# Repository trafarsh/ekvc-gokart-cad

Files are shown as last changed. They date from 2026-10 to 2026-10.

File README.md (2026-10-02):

# EKVC Season 4 – 10 engine-kart concepts (side-mounted Yamaha R15 V2)

Ten complete, rule-checked go-kart designs for the **Engine/Electric Kart Vehicle Championship –
Season 4** rulebook, generated parametrically from the team's Ackermann/layout sketch
(`therika2` / `mutusami_sterring.SLDPRT`).

Each style is a full kart: chromoly frame and roll hoop, **front, rear and side bumpers**,
**chassis-to-bumper connectors**, **single-disc hydraulic brake**, live axle and chain drive, the
R15 V2 engine on the right, Ackermann steering, CBA pedal box, seat, firewall, floor pan, bodywork,
kill switches, brake light, extinguisher, fuel tank, radiator, exhaust, and hitch points.

| | Common to all 10 styles |
|---|---|
| Overall length | **64.1 – 64.6 in bumper face to bumper face, foam included** (limit < 65 in, ≥ 11 mm margin on every kart); nothing protrudes beyond the bumpers |
| Wheelbase / track | 46.0 – 47.0 in wheelbase; front track 36 – 38 in, rear track 42.0 – 42.8 in (rear stays under 50 in even over the tyres) |
| Frame tube | **AISI 4130 chromoly, seamless, 25.4 × 1.65 mm** (rule: 1–2 in OD, ≥ 1.2 mm wall, C ≥ 0.18 %) |
| Engine | Yamaha R15 V2, 149.8 cc single-cylinder 4-stroke, liquid cooled – mounted on the **right**, chain on its inboard side |
| Drive | #428 chain 14T / 34T (66 links), live 40 mm axle, 3 flange bearings |
| Brake | Hydraulic, one 180 mm disc on the live axle (locks both rear wheels), 5/8 in master cylinder with own reservoir, over-travel switch |
| Steering | Column + pitman arm + 2 tie rods, knuckle arms tuned per style for ~100 % Ackermann at lock (computed at the real rod-end ball centres), outer-wheel turning radius ≈ 2.8 m (rule ≤ 3 m), 280 mm round wheel, positive stops on the chassis at 52° column rotation (full lock 49–51°) |
| Driver | Designed around a 175 cm driver: back angle 20°, roll-hoop top 115 mm above the helmet (rule ≥ 76 mm), foot guard 92 mm above the toes (rule ≥ 76 mm) |
| Tyres | 4.5×10.0-5 front, 7.1×11.0-5 rear (rule table 1, dry D1) |

## The ten styles

| Code | Name | Frame idea | Front / rear / side bumpers | Body |
|---|---|---|---|---|
| S01 | Classic Sprint | straight rails, 3-cross ladder | straight / straight / bar | box nose & pods |
| S02 | Arrow | rails taper into the nose + arrow-shaped outer rails | chevron / arc / kicked bar | arrow nose, wedge pods |
| S03 | Ladder Pro | 5-cross ladder + upper side-impact rails | U (up-turned ends) / U / twin-bar | box |
| S04 | Bowfin | left rail bowed outward + floor X | arc / arc / arc | round |
| S05 | X-Brace | X bracing in cockpit and engine bay | trapezoid / trapezoid / bar | wedge |
| S06 | Perimeter | outer perimeter rails carry the side bumpers | wide straight / straight / hoop | box nose, full pods |
| S07 | Spine | centre spine + V outriggers | chevron / straight / bar | F1 nose, slim pods |
| S08 | Endurance | ladder + upper rails + floor/foot-guard/engine-bay diagonals | U / U / twin-bar | round nose, full pods |
| S09 | Featherweight | minimum members | straight / straight / bar | slim |
| S10 | Wedge | plan-view wedge outer rails | swept / arc / swept | wedge |

Each style folder has its own `README.md` with the full **rule-compliance table**, steering
data, interference-check results and renders (`output/<style>/renders/`).

**Check results (all ten styles):** 45 / 45 automated rule checks pass, **0 part-to-part clashes**
(intended welds and bolted joints excluded), **0 contacts** when both front tyres are swept
lock-to-lock against the frame, bumpers, connectors, steering and bodywork, and **0 contacts** when the
whole steering linkage (column, wheel, pitman arm, tie rods, knuckles, hubs, rims, tyres) is moved
lock-to-lock exactly as the SolidWorks live-steering mates move it. The 175 cm reference driver has
no interference with anything except the seat and steering-wheel grips.

## Getting SolidWorks `.SLDPRT` / `.SLDASM` files

SolidWorks' native format can only be written by SolidWorks itself, so every part is delivered
as a STEP file (AP214, millimetres, with names and colours) plus a macro that converts the whole
set inside SolidWorks in one run:

1. In SolidWorks: **Tools ▸ Options ▸ System Options ▸ Import** → untick **Enable 3D Interconnect**
   (so STEP files open as plain imported bodies). Optionally set *Import diagnostics* to "never".
2. **Tools ▸ Macro ▸ New…** (save the new macro anywhere) → in the VBA editor **File ▸ Import File…**
   → choose `solidworks_macro/EKVC_STEP_to_SLDPRT_and_SLDASM.bas` → run `main`.
3. When asked, paste the path of this repository's `output` folder.

The macro saves an `.SLDPRT` next to every `.step` and then builds
`output/<style>/<style>.SLDASM` for all ten karts from `placements.csv`, with every component
fixed in place. Re-running skips files that already exist.

*Quick alternative:* **File ▸ Open** any `output/<style>/<style>_ASSEMBLY.step` → SolidWorks imports
the whole kart as an assembly; **File ▸ Save As** then saves the `.SLDASM` and all part files
(this route gives a static assembly - no live steering).

### Live steering in SolidWorks (turn the wheel, the front wheels steer)

The macro also turns every `.SLDASM` into a working steering mechanism, using
`output/<style>/kinematics.csv`:

| Moving part | How it is mated |
|---|---|
| Steering column | revolute about the column axis (point coincident + point on axis, to the frame) |
| Steering wheel, pitman arm | locked to the column |
| Knuckle L / R | revolute about its king-pin axis |
| Front hub, rim, tyre | locked to their knuckle |
| Tie rod L / R | ball joint at each rod-end centre (pitman arm and knuckle arm) |
| Steering lock | `LimitDistance` mate stops the column at full lock (≈ ±49–51°) |

The joint points and axes are tiny 3D sketches named `KIN_...` that the macro adds to the frame,
column, pitman arm, knuckles and tie rods. **To steer: drag the steering wheel (or a front tyre) with the
left mouse button.** Everything else stays fixed. Hide the joint sketches with *View ▸ Hide/Show ▸ Sketches*.
For an animation, add a *Motion Study* with a rotary motor on the steering column.

Already built the assemblies? Run the macro entry **`live_steering`** instead of `main` to add only the
steering mates. If a mate cannot be made, the end-of-run message lists it (nothing else is changed).
If the steering will not turn at all, suppress the `LimitDistance1` mate: that mate is only the lock stop.

## Repository layout

```
output/
  common/parts/*.step              parts shared by all styles (engine, wheels, brake, pedals, seat ...)
                                   + loose items: C-STD-01 kart stand (rule 8, rails at 950 mm),
                                     C-HIT-02 yellow push-pull rod (rule 1.4)
  S01_ClassicSprint/
    S01_ClassicSprint_ASSEMBLY.step complete kart assembly
    parts/*.step                   style-specific parts (frame, bumpers, connectors, knuckles, body ...)
    placements.csv                 transform of every component (used by the macro)
    kinematics.csv                 joint points/axes + mates for live steering (used by the macro)
    BOM.csv                        bill of materials with materials and notes
    README.md                      rule-compliance report, steering data, clash results
    renders/*.png
  ... S02 – S10
solidworks_macro/EKVC_STEP_to_SLDPRT_and_SLDASM.bas
generator/                          Python/CadQuery source that builds everything
docs/                               source sketch analysis, rule interpretation notes
```

### Coordinate system (all parts and assemblies)

Origin on the ground, on the kart centre-line, directly under the rear axle.
**+X forward, +Y up, +Z to the driver's right (engine side).** Units: mm.
(SolidWorks shows +Y as up, so the karts open the right way up.)

## Regenerating / changing the designs

```bash
pip install cadquery
cd generator
python build_all.py            # all 10 styles with full checks (~25 min)
python build_all.py S04        # one style
python build_all.py --fast S04 # skip the slow interference check
```

Global parameters (tube size, driver package, engine position, steering arm length...) live in
`generator/ekvc/layout.py`; the ten styles are in `generator/ekvc/styles.py`; frame topologies in
`generator/ekvc/parts/frame.py`; bumpers and connectors in `generator/ekvc/parts/bumpers.py`.
Changing the tube (e.g. to AISI 1018, 25.4 × 2.0) is a two-line edit (`TUBE_WALL`, `TUBE_MAT`).

## Important assumptions – please verify

* **Engine envelope.** The R15 V2 is modelled as a dimensional envelope (crankcase, inclined
  cylinder, head, covers, countershaft, mounting lugs). Measure your engine and adjust
  `parts/wheels_drive.py:engine()` and the mount positions before cutting tabs.
* **Your sketch was a 2D layout.** Its wheelbase (51 in) and overall length (73.3 in) did not fit the
  65 in limit, so the wheelbase was shortened to 46–47 in and the Ackermann arm angle re-solved per
  style. The king-pin offset from the wheel (3.52 in) and tyre sizes come from your sketch.
* **Track width rule.** "Larger track ≤ 50 in" is satisfied centre-to-centre *and* over the tyre
  sidewalls (49.9 in max), in case judges measure outside-to-outside.
* **Hoop braces** run rearward from the hoop bend (650 mm) to the rear bulkhead. If your scrutineers
  want them attached higher, raise `HOOP_KNEE_Y` in `layout.py`.
* Bodywork is a 3 mm shell for fit/visual purposes; real panels need mounting brackets.
* Bumper foam is modelled as a continuous sleeve; in practice slit it around the connector tabs and bolts.
* The orange manikin (`REF driver`) is reference geometry only – suppress it before drawings/BOM.
* The live-steering macro was written against the SolidWorks API but could not be run here (no
  SolidWorks in the build environment); the motion it reproduces is verified in Python (see the
  linkage sweep in each style's `README.md`).

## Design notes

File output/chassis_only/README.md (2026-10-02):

# Chassis only - all 10 styles

One STEP part per kart: the welded chromoly frame with roll hoop, hoop braces, foot guard, bulkheads, front axle beam with king-pin C-brackets, jack pads, radiator tabs and the chassis-side bumper connector tabs. No bumpers, bodywork or components.

Tube: AISI 4130 chromoly, seamless, 25.4 x 1.65 mm. Coordinates are the same as the full karts (origin on the ground under the rear axle, +X forward, +Y up, +Z right), so each chassis drops straight into the kart assembly.

**To get .SLDPRT:** SolidWorks > File > Open > pick the .step > File > Save As > Part (*.sldprt). It opens as a multi-body part (one body per tube / plate), like a weldment.

| Kart | File | Tube bodies + plates | Connector tabs | Size L x H x W (mm) | Tube length | Tube mass |
|---|---|---|---|---|---|---|
| S01 Classic Sprint | `S01_ClassicSprint_Chassis.step` | 33 | 8 | 1555 x 1035 x 1186 | 17.8 m | 17.2 kg |
| S02 Arrow | `S02_Arrow_Chassis.step` | 33 | 8 | 1550 x 1035 x 1185 | 18.3 m | 17.7 kg |
| S03 Ladder Pro | `S03_LadderPro_Chassis.step` | 36 | 8 | 1555 x 1035 x 1186 | 19.6 m | 19.0 kg |
| S04 Bowfin | `S04_Bowfin_Chassis.step` | 34 | 8 | 1550 x 1035 x 1231 | 18.3 m | 17.7 kg |
| S05 X-Brace | `S05_X-Brace_Chassis.step` | 37 | 8 | 1553 x 1035 x 1185 | 19.7 m | 19.0 kg |
| S06 Perimeter | `S06_Perimeter_Chassis.step` | 35 | 8 | 1555 x 1035 x 1186 | 19.3 m | 18.6 kg |
| S07 Spine | `S07_Spine_Chassis.step` | 35 | 8 | 1549 x 1035 x 1185 | 18.5 m | 17.9 kg |
| S08 Endurance | `S08_Endurance_Chassis.step` | 39 | 8 | 1555 x 1035 x 1186 | 20.7 m | 20.0 kg |
| S09 Featherweight | `S09_Featherweight_Chassis.step` | 31 | 8 | 1547 x 1035 x 1185 | 16.9 m | 16.3 kg |
| S10 Wedge | `S10_Wedge_Chassis.step` | 33 | 8 | 1552 x 1035 x 1178 | 18.3 m | 17.7 kg |

Renders: `renders/` (iso, side, top for each kart; `all_chassis_iso.png` shows all ten).

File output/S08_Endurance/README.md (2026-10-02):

# S08 - Endurance

Heavily triangulated with upper side rails and diagonal floor braces; built for the endurance event.

* Wheelbase **47.00 in** (1193.8 mm), front track 37.50 in, rear track 42.80 in
* Frame: `endurance` - 20.7 m of 25.4 x 1.65 mm AISI 4130 chromoly, seamless (C 0.28-0.33 %) (~20.0 kg tube)
* Bumpers: front `U`, rear `U`, side `double`; body: nose `round`, pods `full`
* Steering: arm 155 mm at 15.25 deg, tie rods 277/396 mm (solver), lock inner 33.9 / outer 25.2 deg, R(outer front) 2.81 m, Ackermann 99 %

## Rule compliance (EKVC Season 4)

| Rule | Check | Requirement | This kart | Result |
|---|---|---|---|---|
| 1.1 | Wheelbase | <= 60 in (1524 mm) | 1193.8 mm (47.00 in) | ✅ PASS |
| 1.1 | Larger track (centre-to-centre) | <= 50 in (1270 mm) | 1087.1 mm (42.80 in) | ✅ PASS |
| 1.1 | Rear track outside-to-outside (conservative) | <= 50 in | 1267.5 mm (49.90 in) | ✅ PASS |
| 1.1 | Wheels not in line longitudinally | front track != rear track | F 952 / R 1087 mm | ✅ PASS |
| User | Front bumper to rear bumper (incl. foam) | < 65 in (1651 mm) | 1635.9 mm (64.41 in) | ✅ PASS |
| User | Overall length (any component) | < 65 in, nothing beyond bumpers | 1635.9 mm (64.41 in) | ✅ PASS |
| info | Overall width | (info) | 1320 mm (52.0 in) | ✅ PASS |
| 1.2 | Frame tube OD / wall | 1-2 in OD, >= 1.2 mm wall, seamless round | 25.4 x 1.65 mm, AISI 4130 chromoly, seamless (C 0.28-0.33 %) | ✅ PASS |
| 1.2 | Open tube end capped | >= 1 open end, capped | Silencer-stay end capped (6 mm plug) | ✅ PASS |
| 1.3 | Ground clearance (lowest non-tyre point) | 1-2 in (25.4-50.8 mm) | 35.0 mm (Firewall rear) | ✅ PASS |
| 1.4 | Hitch points | front + rear, not on bumper, yellow | 2 eyes on bulkhead tubes | ✅ PASS |
| 1.5 | Roll hoop height above helmet (175 cm driver) | >= 3 in (76.2 mm) | 115.0 mm | ✅ PASS |
| 1.5 | Roll hoop construction | one bent tube + 2 braces L/R | single bent tube, 2 rearward braces + cross bar | ✅ PASS |
| 1.6 | Front bumper ahead of front bulkhead | >= 4 in (101.6 mm) | 114.7 mm | ✅ PASS |
| 1.6 | Rear bumper behind rear bulkhead | >= 2 in (50.8 mm) | 56.8 mm | ✅ PASS |
| 1.6 | Bumpers cover tyres laterally | bumper reaches outer tyre edge | front +22 mm, rear +4 mm | ✅ PASS |
| 7.1.1 | No full-round bumper | side bumpers separate from front/rear | min X gap 344 mm | ✅ PASS |
| 1.6 | Bumper padding | foam pipe insulation | 12 mm closed-cell foam on all bumpers | ✅ PASS |
| 2.2 | Tyres | F 4.5x10.0-5, R 7.1x11.0-5 (D1) | as specified, 4 wheels | ✅ PASS |
| 3.1 | Seat | bucket seat, >= 4 mounts on primary members, lock nuts | GRP bucket, 4 mounts | ✅ PASS |
| 3.2 | Foot guard above toe | >= 3 in (76.2 mm) + anti-intrusion plate | 91.7 mm, 2 mm Al plate | ✅ PASS |
| 3.3 | Back angle | <= 30 deg from vertical | 20 deg | ✅ PASS |
| 3.5 | Firewall | >= 1.5 mm Al, no holes, nothing mounted | 1.5 mm 5052 side + rear panels | ✅ PASS |
| 4.1 | Steering mechanism | mechanical, no rack & pinion / by-wire | column + pitman arm + 2 tie rods (Ackermann) | ✅ PASS |
| 4.2 | Steering wheel | >= 10 in OD full circle | 280 mm round | ✅ PASS |
| 4.3 | Steering stops | positive stops on chassis | 2 adjustable stops on column lower bracket | ✅ PASS |
| 4.4 | Turning radius (outer front wheel) | <= 3 m | L 2.81 m / R 2.83 m | ✅ PASS |
| info | Ackermann at lock | (design target ~100 %) | 99 % (inner 33.9 / outer 25.2 deg) | ✅ PASS |
| 5.1 | Brake system | hydraulic, acts on both rear wheels | single 180 mm disc on live axle, twin-piston caliper | ✅ PASS |
| 5.2 | Brake pedal | foot operated, steel/Al, travel stop | AISI 4130 pedal with stop | ✅ PASS |
| 5.3 | Brake over-travel switch | in series with kill switches | fitted ahead of pedal | ✅ PASS |
| 5.6 | Brake light | red, top centre of roll hoop | LED on hoop top centre | ✅ PASS |
| 6.2.1 | Engine | single cyl 4-stroke petrol <= 160 cc | Yamaha R15 V2 149.8 cc liquid cooled | ✅ PASS |
| 6.2.2 | Engine mounting tabs | >= 5 mm + damping | 6 mm tabs + rubber isolators | ✅ PASS |
| 6.2.3 | Fuel tank | <= 3 L, side-engine fuel area | 2.79 L behind seat (left) | ✅ PASS |
| 6.2.3 | Radiator | behind firewall | behind rear firewall, above axle | ✅ PASS |
| 6.2.4 | Exhaust outlet | behind driver, <= 650 mm high | X -186 mm, height 370 mm | ✅ PASS |
| 6.4 | Transmission | chain drive, RWD, scatter shield | #428 chain 14/34, Al scatter shield | ✅ PASS |
| 6.4.2 | Pedal layout | C-B-A left to right, throttle stop | clutch / brake / throttle | ✅ PASS |
| 6.5 | Kill switches | >= 2 (driver + both sides of hoop), red | 3 fitted | ✅ PASS |
| 6.9 | Fire extinguisher | 1 kg in cockpit, not on firewall | 1 kg ABC on left main rail | ✅ PASS |
| 6.10 | Fasteners | metal, grade 8.8, lock nuts | M8 8.8 + nyloc on all connectors | ✅ PASS |
| 7.1 | Bodywork | front (to steering wheel), L/R sides, rear | nose + 2 pods + rear panel | ✅ PASS |
| 7.1.2 | Floor close-out | >= 1 mm rigid, firewall to front | 2.0 mm aluminium | ✅ PASS |
| 9 | Number stickers | 6 in yellow: front, both sides, rear | 4 fitted | ✅ PASS |

## Interference check

* Part-to-part clashes (excluding intended welds/bolted contacts): **0**
* Driver (175 cm reference manikin) contacts: 0
* Front tyres swept lock-to-lock against frame/bumpers/body/steering: **0** contacts
* Whole steering linkage (column, wheel, pitman arm, tie rods, knuckles, hubs, rims, tyres) moved lock-to-lock (column -50.8 to +50.8 deg), exactly as the SolidWorks live-steering mates move it: **0** new contacts

## Files

* Assembly STEP: `S08_Endurance_ASSEMBLY.step`
* Placement table (SolidWorks macro): `placements.csv`
* Live-steering mates (SolidWorks macro): `kinematics.csv`
* Bill of materials: `BOM.csv`
* Render iso: `renders/S08_iso.png`
* Render iso_rear: `renders/S08_iso_rear.png`
* Render top: `renders/S08_top.png`
* Render side: `renders/S08_side.png`
* Render side_driver: `renders/S08_side_driver.png`

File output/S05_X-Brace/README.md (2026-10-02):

# S05 - X-Brace

Full-length X bracing between the main rails for torsional stiffness; trapezoid bumpers.

* Wheelbase **46.00 in** (1168.4 mm), front track 36.00 in, rear track 42.00 in
* Frame: `xbrace` - 19.7 m of 25.4 x 1.65 mm AISI 4130 chromoly, seamless (C 0.28-0.33 %) (~19.0 kg tube)
* Bumpers: front `trapezoid`, rear `trapezoid`, side `bar`; body: nose `wedge`, pods `wedge`
* Steering: arm 155 mm at 15.25 deg, tie rods 258/377 mm (solver), lock inner 32.6 / outer 24.5 deg, R(outer front) 2.82 m, Ackermann 100 %

## Rule compliance (EKVC Season 4)

| Rule | Check | Requirement | This kart | Result |
|---|---|---|---|---|
| 1.1 | Wheelbase | <= 60 in (1524 mm) | 1168.4 mm (46.00 in) | ✅ PASS |
| 1.1 | Larger track (centre-to-centre) | <= 50 in (1270 mm) | 1066.8 mm (42.00 in) | ✅ PASS |
| 1.1 | Rear track outside-to-outside (conservative) | <= 50 in | 1247.1 mm (49.10 in) | ✅ PASS |
| 1.1 | Wheels not in line longitudinally | front track != rear track | F 914 / R 1067 mm | ✅ PASS |
| User | Front bumper to rear bumper (incl. foam) | < 65 in (1651 mm) | 1633.8 mm (64.32 in) | ✅ PASS |
| User | Overall length (any component) | < 65 in, nothing beyond bumpers | 1633.8 mm (64.32 in) | ✅ PASS |
| info | Overall width | (info) | 1309 mm (51.5 in) | ✅ PASS |
| 1.2 | Frame tube OD / wall | 1-2 in OD, >= 1.2 mm wall, seamless round | 25.4 x 1.65 mm, AISI 4130 chromoly, seamless (C 0.28-0.33 %) | ✅ PASS |
| 1.2 | Open tube end capped | >= 1 open end, capped | Silencer-stay end capped (6 mm plug) | ✅ PASS |
| 1.3 | Ground clearance (lowest non-tyre point) | 1-2 in (25.4-50.8 mm) | 35.0 mm (Firewall rear) | ✅ PASS |
| 1.4 | Hitch points | front + rear, not on bumper, yellow | 2 eyes on bulkhead tubes | ✅ PASS |
| 1.5 | Roll hoop height above helmet (175 cm driver) | >= 3 in (76.2 mm) | 115.0 mm | ✅ PASS |
| 1.5 | Roll hoop construction | one bent tube + 2 braces L/R | single bent tube, 2 rearward braces + cross bar | ✅ PASS |
| 1.6 | Front bumper ahead of front bulkhead | >= 4 in (101.6 mm) | 106.6 mm | ✅ PASS |
| 1.6 | Rear bumper behind rear bulkhead | >= 2 in (50.8 mm) | 56.8 mm | ✅ PASS |
| 1.6 | Bumpers cover tyres laterally | bumper reaches outer tyre edge | front +22 mm, rear +4 mm | ✅ PASS |
| 7.1.1 | No full-round bumper | side bumpers separate from front/rear | min X gap 329 mm | ✅ PASS |
| 1.6 | Bumper padding | foam pipe insulation | 12 mm closed-cell foam on all bumpers | ✅ PASS |
| 2.2 | Tyres | F 4.5x10.0-5, R 7.1x11.0-5 (D1) | as specified, 4 wheels | ✅ PASS |
| 3.1 | Seat | bucket seat, >= 4 mounts on primary members, lock nuts | GRP bucket, 4 mounts | ✅ PASS |
| 3.2 | Foot guard above toe | >= 3 in (76.2 mm) + anti-intrusion plate | 91.7 mm, 2 mm Al plate | ✅ PASS |
| 3.3 | Back angle | <= 30 deg from vertical | 20 deg | ✅ PASS |
| 3.5 | Firewall | >= 1.5 mm Al, no holes, nothing mounted | 1.5 mm 5052 side + rear panels | ✅ PASS |
| 4.1 | Steering mechanism | mechanical, no rack & pinion / by-wire | column + pitman arm + 2 tie rods (Ackermann) | ✅ PASS |
| 4.2 | Steering wheel | >= 10 in OD full circle | 280 mm round | ✅ PASS |
| 4.3 | Steering stops | positive stops on chassis | 2 adjustable stops on column lower bracket | ✅ PASS |
| 4.4 | Turning radius (outer front wheel) | <= 3 m | L 2.82 m / R 2.83 m | ✅ PASS |
| info | Ackermann at lock | (design target ~100 %) | 100 % (inner 32.6 / outer 24.5 deg) | ✅ PASS |
| 5.1 | Brake system | hydraulic, acts on both rear wheels | single 180 mm disc on live axle, twin-piston caliper | ✅ PASS |
| 5.2 | Brake pedal | foot operated, steel/Al, travel stop | AISI 4130 pedal with stop | ✅ PASS |
| 5.3 | Brake over-travel switch | in series with kill switches | fitted ahead of pedal | ✅ PASS |
| 5.6 | Brake light | red, top centre of roll hoop | LED on hoop top centre | ✅ PASS |
| 6.2.1 | Engine | single cyl 4-stroke petrol <= 160 cc | Yamaha R15 V2 149.8 cc liquid cooled | ✅ PASS |
| 6.2.2 | Engine mounting tabs | >= 5 mm + damping | 6 mm tabs + rubber isolators | ✅ PASS |
| 6.2.3 | Fuel tank | <= 3 L, side-engine fuel area | 2.79 L behind seat (left) | ✅ PASS |
| 6.2.3 | Radiator | behind firewall | behind rear firewall, above axle | ✅ PASS |
| 6.2.4 | Exhaust outlet | behind driver, <= 650 mm high | X -186 mm, height 370 mm | ✅ PASS |
| 6.4 | Transmission | chain drive, RWD, scatter shield | #428 chain 14/34, Al scatter shield | ✅ PASS |
| 6.4.2 | Pedal layout | C-B-A left to right, throttle stop | clutch / brake / throttle | ✅ PASS |
| 6.5 | Kill switches | >= 2 (driver + both sides of hoop), red | 3 fitted | ✅ PASS |
| 6.9 | Fire extinguisher | 1 kg in cockpit, not on firewall | 1 kg ABC on left main rail | ✅ PASS |
| 6.10 | Fasteners | metal, grade 8.8, lock nuts | M8 8.8 + nyloc on all connectors | ✅ PASS |
| 7.1 | Bodywork | front (to steering wheel), L/R sides, rear | nose + 2 pods + rear panel | ✅ PASS |
| 7.1.2 | Floor close-out | >= 1 mm rigid, firewall to front | 2.0 mm aluminium | ✅ PASS |
| 9 | Number stickers | 6 in yellow: front, both sides, rear | 4 fitted | ✅ PASS |

## Interference check

* Part-to-part clashes (excluding intended welds/bolted contacts): **0**
* Driver (175 cm reference manikin) contacts: 0
* Front tyres swept lock-to-lock against frame/bumpers/body/steering: **0** contacts
* Whole steering linkage (column, wheel, pitman arm, tie rods, knuckles, hubs, rims, tyres) moved lock-to-lock (column -48.8 to +48.8 deg), exactly as the SolidWorks live-steering mates move it: **0** new contacts

## Files

* Assembly STEP: `S05_X-Brace_ASSEMBLY.step`
* Placement table (SolidWorks macro): `placements.csv`
* Live-steering mates (SolidWorks macro): `kinematics.csv`
* Bill of materials: `BOM.csv`
* Render iso: `renders/S05_iso.png`
* Render iso_rear: `renders/S05_iso_rear.png`
* Render top: `renders/S05_top.png`
* Render side: `renders/S05_side.png`
* Render side_driver: `renders/S05_side_driver.png`

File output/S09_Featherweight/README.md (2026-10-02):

# S09 - Featherweight

Fewest members and shortest overall length - the light-weight option.

* Wheelbase **46.00 in** (1168.4 mm), front track 36.00 in, rear track 42.00 in
* Frame: `minimal` - 16.9 m of 25.4 x 1.65 mm AISI 4130 chromoly, seamless (C 0.28-0.33 %) (~16.3 kg tube)
* Bumpers: front `straight`, rear `straight`, side `bar`; body: nose `slim`, pods `slim`
* Steering: arm 155 mm at 15.25 deg, tie rods 258/377 mm (solver), lock inner 32.6 / outer 24.5 deg, R(outer front) 2.82 m, Ackermann 100 %

## Rule compliance (EKVC Season 4)

| Rule | Check | Requirement | This kart | Result |
|---|---|---|---|---|
| 1.1 | Wheelbase | <= 60 in (1524 mm) | 1168.4 mm (46.00 in) | ✅ PASS |
| 1.1 | Larger track (centre-to-centre) | <= 50 in (1270 mm) | 1066.8 mm (42.00 in) | ✅ PASS |
| 1.1 | Rear track outside-to-outside (conservative) | <= 50 in | 1247.1 mm (49.10 in) | ✅ PASS |
| 1.1 | Wheels not in line longitudinally | front track != rear track | F 914 / R 1067 mm | ✅ PASS |
| User | Front bumper to rear bumper (incl. foam) | < 65 in (1651 mm) | 1627.8 mm (64.09 in) | ✅ PASS |
| User | Overall length (any component) | < 65 in, nothing beyond bumpers | 1627.8 mm (64.09 in) | ✅ PASS |
| info | Overall width | (info) | 1286 mm (50.6 in) | ✅ PASS |
| 1.2 | Frame tube OD / wall | 1-2 in OD, >= 1.2 mm wall, seamless round | 25.4 x 1.65 mm, AISI 4130 chromoly, seamless (C 0.28-0.33 %) | ✅ PASS |
| 1.2 | Open tube end capped | >= 1 open end, capped | Silencer-stay end capped (6 mm plug) | ✅ PASS |
| 1.3 | Ground clearance (lowest non-tyre point) | 1-2 in (25.4-50.8 mm) | 35.0 mm (Firewall rear) | ✅ PASS |
| 1.4 | Hitch points | front + rear, not on bumper, yellow | 2 eyes on bulkhead tubes | ✅ PASS |
| 1.5 | Roll hoop height above helmet (175 cm driver) | >= 3 in (76.2 mm) | 115.0 mm | ✅ PASS |
| 1.5 | Roll hoop construction | one bent tube + 2 braces L/R | single bent tube, 2 rearward braces + cross bar | ✅ PASS |
| 1.6 | Front bumper ahead of front bulkhead | >= 4 in (101.6 mm) | 106.6 mm | ✅ PASS |
| 1.6 | Rear bumper behind rear bulkhead | >= 2 in (50.8 mm) | 56.8 mm | ✅ PASS |
| 1.6 | Bumpers cover tyres laterally | bumper reaches outer tyre edge | front +22 mm, rear +4 mm | ✅ PASS |
| 7.1.1 | No full-round bumper | side bumpers separate from front/rear | min X gap 332 mm | ✅ PASS |
| 1.6 | Bumper padding | foam pipe insulation | 12 mm closed-cell foam on all bumpers | ✅ PASS |
| 2.2 | Tyres | F 4.5x10.0-5, R 7.1x11.0-5 (D1) | as specified, 4 wheels | ✅ PASS |
| 3.1 | Seat | bucket seat, >= 4 mounts on primary members, lock nuts | GRP bucket, 4 mounts | ✅ PASS |
| 3.2 | Foot guard above toe | >= 3 in (76.2 mm) + anti-intrusion plate | 91.7 mm, 2 mm Al plate | ✅ PASS |
| 3.3 | Back angle | <= 30 deg from vertical | 20 deg | ✅ PASS |
| 3.5 | Firewall | >= 1.5 mm Al, no holes, nothing mounted | 1.5 mm 5052 side + rear panels | ✅ PASS |
| 4.1 | Steering mechanism | mechanical, no rack & pinion / by-wire | column + pitman arm + 2 tie rods (Ackermann) | ✅ PASS |
| 4.2 | Steering wheel | >= 10 in OD full circle | 280 mm round | ✅ PASS |
| 4.3 | Steering stops | positive stops on chassis | 2 adjustable stops on column lower bracket | ✅ PASS |
| 4.4 | Turning radius (outer front wheel) | <= 3 m | L 2.82 m / R 2.83 m | ✅ PASS |
| info | Ackermann at lock | (design target ~100 %) | 100 % (inner 32.6 / outer 24.5 deg) | ✅ PASS |
| 5.1 | Brake system | hydraulic, acts on both rear wheels | single 180 mm disc on live axle, twin-piston caliper | ✅ PASS |
| 5.2 | Brake pedal | foot operated, steel/Al, travel stop | AISI 4130 pedal with stop | ✅ PASS |
| 5.3 | Brake over-travel switch | in series with kill switches | fitted ahead of pedal | ✅ PASS |
| 5.6 | Brake light | red, top centre of roll hoop | LED on hoop top centre | ✅ PASS |
| 6.2.1 | Engine | single cyl 4-stroke petrol <= 160 cc | Yamaha R15 V2 149.8 cc liquid cooled | ✅ PASS |
| 6.2.2 | Engine mounting tabs | >= 5 mm + damping | 6 mm tabs + rubber isolators | ✅ PASS |
| 6.2.3 | Fuel tank | <= 3 L, side-engine fuel area | 2.79 L behind seat (left) | ✅ PASS |
| 6.2.3 | Radiator | behind firewall | behind rear firewall, above axle | ✅ PASS |
| 6.2.4 | Exhaust outlet | behind driver, <= 650 mm high | X -186 mm, height 370 mm | ✅ PASS |
| 6.4 | Transmission | chain drive, RWD, scatter shield | #428 chain 14/34, Al scatter shield | ✅ PASS |
| 6.4.2 | Pedal layout | C-B-A left to right, throttle stop | clutch / brake / throttle | ✅ PASS |
| 6.5 | Kill switches | >= 2 (driver + both sides of hoop), red | 3 fitted | ✅ PASS |
| 6.9 | Fire extinguisher | 1 kg in cockpit, not on firewall | 1 kg ABC on left main rail | ✅ PASS |
| 6.10 | Fasteners | metal, grade 8.8, lock nuts | M8 8.8 + nyloc on all connectors | ✅ PASS |
| 7.1 | Bodywork | front (to steering wheel), L/R sides, rear | nose + 2 pods + rear panel | ✅ PASS |
| 7.1.2 | Floor close-out | >= 1 mm rigid, firewall to front | 2.0 mm aluminium | ✅ PASS |
| 9 | Number stickers | 6 in yellow: front, both sides, rear | 4 fitted | ✅ PASS |

## Interference check

* Part-to-part clashes (excluding intended welds/bolted contacts): **0**
* Driver (175 cm reference manikin) contacts: 0
* Front tyres swept lock-to-lock against frame/bumpers/body/steering: **0** contacts
* Whole steering linkage (column, wheel, pitman arm, tie rods, knuckles, hubs, rims, tyres) moved lock-to-lock (column -48.8 to +48.8 deg), exactly as the SolidWorks live-steering mates move it: **0** new contacts

## Files

* Assembly STEP: `S09_Featherweight_ASSEMBLY.step`
* Placement table (SolidWorks macro): `placements.csv`
* Live-steering mates (SolidWorks macro): `kinematics.csv`
* Bill of materials: `BOM.csv`
* Render iso: `renders/S09_iso.png`
* Render iso_rear: `renders/S09_iso_rear.png`
* Render top: `renders/S09_top.png`
* Render side: `renders/S09_side.png`
* Render side_driver: `renders/S09_side_driver.png`

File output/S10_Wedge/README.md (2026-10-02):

# S10 - Wedge

Plan-view wedge: wide at the engine bay, narrowing to the nose, with swept side bumpers.

* Wheelbase **46.00 in** (1168.4 mm), front track 36.50 in, rear track 42.80 in
* Frame: `wedge` - 18.3 m of 25.4 x 1.65 mm AISI 4130 chromoly, seamless (C 0.28-0.33 %) (~17.7 kg tube)
* Bumpers: front `swept`, rear `arc`, side `swept`; body: nose `wedge`, pods `wedge`
* Steering: arm 155 mm at 15.50 deg, tie rods 263/383 mm (solver), lock inner 32.7 / outer 24.5 deg, R(outer front) 2.82 m, Ackermann 99 %

## Rule compliance (EKVC Season 4)

| Rule | Check | Requirement | This kart | Result |
|---|---|---|---|---|
| 1.1 | Wheelbase | <= 60 in (1524 mm) | 1168.4 mm (46.00 in) | ✅ PASS |
| 1.1 | Larger track (centre-to-centre) | <= 50 in (1270 mm) | 1087.1 mm (42.80 in) | ✅ PASS |
| 1.1 | Rear track outside-to-outside (conservative) | <= 50 in | 1267.5 mm (49.90 in) | ✅ PASS |
| 1.1 | Wheels not in line longitudinally | front track != rear track | F 927 / R 1087 mm | ✅ PASS |
| User | Front bumper to rear bumper (incl. foam) | < 65 in (1651 mm) | 1639.8 mm (64.56 in) | ✅ PASS |
| User | Overall length (any component) | < 65 in, nothing beyond bumpers | 1639.8 mm (64.56 in) | ✅ PASS |
| info | Overall width | (info) | 1311 mm (51.6 in) | ✅ PASS |
| 1.2 | Frame tube OD / wall | 1-2 in OD, >= 1.2 mm wall, seamless round | 25.4 x 1.65 mm, AISI 4130 chromoly, seamless (C 0.28-0.33 %) | ✅ PASS |
| 1.2 | Open tube end capped | >= 1 open end, capped | Silencer-stay end capped (6 mm plug) | ✅ PASS |
| 1.3 | Ground clearance (lowest non-tyre point) | 1-2 in (25.4-50.8 mm) | 35.0 mm (Firewall rear) | ✅ PASS |
| 1.4 | Hitch points | front + rear, not on bumper, yellow | 2 eyes on bulkhead tubes | ✅ PASS |
| 1.5 | Roll hoop height above helmet (175 cm driver) | >= 3 in (76.2 mm) | 115.0 mm | ✅ PASS |
| 1.5 | Roll hoop construction | one bent tube + 2 braces L/R | single bent tube, 2 rearward braces + cross bar | ✅ PASS |
| 1.6 | Front bumper ahead of front bulkhead | >= 4 in (101.6 mm) | 106.6 mm | ✅ PASS |
| 1.6 | Rear bumper behind rear bulkhead | >= 2 in (50.8 mm) | 56.8 mm | ✅ PASS |
| 1.6 | Bumpers cover tyres laterally | bumper reaches outer tyre edge | front +22 mm, rear +4 mm | ✅ PASS |
| 7.1.1 | No full-round bumper | side bumpers separate from front/rear | min X gap 335 mm | ✅ PASS |
| 1.6 | Bumper padding | foam pipe insulation | 12 mm closed-cell foam on all bumpers | ✅ PASS |
| 2.2 | Tyres | F 4.5x10.0-5, R 7.1x11.0-5 (D1) | as specified, 4 wheels | ✅ PASS |
| 3.1 | Seat | bucket seat, >= 4 mounts on primary members, lock nuts | GRP bucket, 4 mounts | ✅ PASS |
| 3.2 | Foot guard above toe | >= 3 in (76.2 mm) + anti-intrusion plate | 91.7 mm, 2 mm Al plate | ✅ PASS |
| 3.3 | Back angle | <= 30 deg from vertical | 20 deg | ✅ PASS |
| 3.5 | Firewall | >= 1.5 mm Al, no holes, nothing mounted | 1.5 mm 5052 side + rear panels | ✅ PASS |
| 4.1 | Steering mechanism | mechanical, no rack & pinion / by-wire | column + pitman arm + 2 tie rods (Ackermann) | ✅ PASS |
| 4.2 | Steering wheel | >= 10 in OD full circle | 280 mm round | ✅ PASS |
| 4.3 | Steering stops | positive stops on chassis | 2 adjustable stops on column lower bracket | ✅ PASS |
| 4.4 | Turning radius (outer front wheel) | <= 3 m | L 2.82 m / R 2.83 m | ✅ PASS |
| info | Ackermann at lock | (design target ~100 %) | 99 % (inner 32.7 / outer 24.5 deg) | ✅ PASS |
| 5.1 | Brake system | hydraulic, acts on both rear wheels | single 180 mm disc on live axle, twin-piston caliper | ✅ PASS |
| 5.2 | Brake pedal | foot operated, steel/Al, travel stop | AISI 4130 pedal with stop | ✅ PASS |
| 5.3 | Brake over-travel switch | in series with kill switches | fitted ahead of pedal | ✅ PASS |
| 5.6 | Brake light | red, top centre of roll hoop | LED on hoop top centre | ✅ PASS |
| 6.2.1 | Engine | single cyl 4-stroke petrol <= 160 cc | Yamaha R15 V2 149.8 cc liquid cooled | ✅ PASS |
| 6.2.2 | Engine mounting tabs | >= 5 mm + damping | 6 mm tabs + rubber isolators | ✅ PASS |
| 6.2.3 | Fuel tank | <= 3 L, side-engine fuel area | 2.79 L behind seat (left) | ✅ PASS |
| 6.2.3 | Radiator | behind firewall | behind rear firewall, above axle | ✅ PASS |
| 6.2.4 | Exhaust outlet | behind driver, <= 650 mm high | X -186 mm, height 370 mm | ✅ PASS |
| 6.4 | Transmission | chain drive, RWD, scatter shield | #428 chain 14/34, Al scatter shield | ✅ PASS |
| 6.4.2 | Pedal layout | C-B-A left to right, throttle stop | clutch / brake / throttle | ✅ PASS |
| 6.5 | Kill switches | >= 2 (driver + both sides of hoop), red | 3 fitted | ✅ PASS |
| 6.9 | Fire extinguisher | 1 kg in cockpit, not on firewall | 1 kg ABC on left main rail | ✅ PASS |
| 6.10 | Fasteners | metal, grade 8.8, lock nuts | M8 8.8 + nyloc on all connectors | ✅ PASS |
| 7.1 | Bodywork | front (to steering wheel), L/R sides, rear | nose + 2 pods + rear panel | ✅ PASS |
| 7.1.2 | Floor close-out | >= 1 mm rigid, firewall to front | 2.0 mm aluminium | ✅ PASS |
| 9 | Number stickers | 6 in yellow: front, both sides, rear | 4 fitted | ✅ PASS |

## Interference check

* Part-to-part clashes (excluding intended welds/bolted contacts): **0**
* Driver (175 cm reference manikin) contacts: 0
* Front tyres swept lock-to-lock against frame/bumpers/body/steering: **0** contacts
* Whole steering linkage (column, wheel, pitman arm, tie rods, knuckles, hubs, rims, tyres) moved lock-to-lock (column -48.8 to +48.8 deg), exactly as the SolidWorks live-steering mates move it: **0** new contacts

## Files

* Assembly STEP: `S10_Wedge_ASSEMBLY.step`
* Placement table (SolidWorks macro): `placements.csv`
* Live-steering mates (SolidWorks macro): `kinematics.csv`
* Bill of materials: `BOM.csv`
* Render iso: `renders/S10_iso.png`
* Render iso_rear: `renders/S10_iso_rear.png`
* Render top: `renders/S10_top.png`
* Render side: `renders/S10_side.png`
* Render side_driver: `renders/S10_side_driver.png`

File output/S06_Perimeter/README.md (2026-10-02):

# S06 - Perimeter

Outer perimeter rails carry the side bumpers; wide straight bumpers and full-length side pods.

* Wheelbase **47.00 in** (1193.8 mm), front track 38.00 in, rear track 42.80 in
* Frame: `perimeter` - 19.3 m of 25.4 x 1.65 mm AISI 4130 chromoly, seamless (C 0.28-0.33 %) (~18.6 kg tube)
* Bumpers: front `straight_wide`, rear `straight`, side `hoop`; body: nose `box`, pods `full`
* Steering: arm 155 mm at 15.75 deg, tie rods 282/402 mm (solver), lock inner 34.2 / outer 25.2 deg, R(outer front) 2.81 m, Ackermann 101 %

## Rule compliance (EKVC Season 4)

| Rule | Check | Requirement | This kart | Result |
|---|---|---|---|---|
| 1.1 | Wheelbase | <= 60 in (1524 mm) | 1193.8 mm (47.00 in) | ✅ PASS |
| 1.1 | Larger track (centre-to-centre) | <= 50 in (1270 mm) | 1087.1 mm (42.80 in) | ✅ PASS |
| 1.1 | Rear track outside-to-outside (conservative) | <= 50 in | 1267.5 mm (49.90 in) | ✅ PASS |
| 1.1 | Wheels not in line longitudinally | front track != rear track | F 965 / R 1087 mm | ✅ PASS |
| User | Front bumper to rear bumper (incl. foam) | < 65 in (1651 mm) | 1635.9 mm (64.41 in) | ✅ PASS |
| User | Overall length (any component) | < 65 in, nothing beyond bumpers | 1635.9 mm (64.41 in) | ✅ PASS |
| info | Overall width | (info) | 1321 mm (52.0 in) | ✅ PASS |
| 1.2 | Frame tube OD / wall | 1-2 in OD, >= 1.2 mm wall, seamless round | 25.4 x 1.65 mm, AISI 4130 chromoly, seamless (C 0.28-0.33 %) | ✅ PASS |
| 1.2 | Open tube end capped | >= 1 open end, capped | Silencer-stay end capped (6 mm plug) | ✅ PASS |
| 1.3 | Ground clearance (lowest non-tyre point) | 1-2 in (25.4-50.8 mm) | 35.0 mm (Firewall rear) | ✅ PASS |
| 1.4 | Hitch points | front + rear, not on bumper, yellow | 2 eyes on bulkhead tubes | ✅ PASS |
| 1.5 | Roll hoop height above helmet (175 cm driver) | >= 3 in (76.2 mm) | 115.0 mm | ✅ PASS |
| 1.5 | Roll hoop construction | one bent tube + 2 braces L/R | single bent tube, 2 rearward braces + cross bar | ✅ PASS |
| 1.6 | Front bumper ahead of front bulkhead | >= 4 in (101.6 mm) | 114.7 mm | ✅ PASS |
| 1.6 | Rear bumper behind rear bulkhead | >= 2 in (50.8 mm) | 56.8 mm | ✅ PASS |
| 1.6 | Bumpers cover tyres laterally | bumper reaches outer tyre edge | front +57 mm, rear +4 mm | ✅ PASS |
| 7.1.1 | No full-round bumper | side bumpers separate from front/rear | min X gap 311 mm | ✅ PASS |
| 1.6 | Bumper padding | foam pipe insulation | 12 mm closed-cell foam on all bumpers | ✅ PASS |
| 2.2 | Tyres | F 4.5x10.0-5, R 7.1x11.0-5 (D1) | as specified, 4 wheels | ✅ PASS |
| 3.1 | Seat | bucket seat, >= 4 mounts on primary members, lock nuts | GRP bucket, 4 mounts | ✅ PASS |
| 3.2 | Foot guard above toe | >= 3 in (76.2 mm) + anti-intrusion plate | 91.7 mm, 2 mm Al plate | ✅ PASS |
| 3.3 | Back angle | <= 30 deg from vertical | 20 deg | ✅ PASS |
| 3.5 | Firewall | >= 1.5 mm Al, no holes, nothing mounted | 1.5 mm 5052 side + rear panels | ✅ PASS |
| 4.1 | Steering mechanism | mechanical, no rack & pinion / by-wire | column + pitman arm + 2 tie rods (Ackermann) | ✅ PASS |
| 4.2 | Steering wheel | >= 10 in OD full circle | 280 mm round | ✅ PASS |
| 4.3 | Steering stops | positive stops on chassis | 2 adjustable stops on column lower bracket | ✅ PASS |
| 4.4 | Turning radius (outer front wheel) | <= 3 m | L 2.81 m / R 2.83 m | ✅ PASS |
| info | Ackermann at lock | (design target ~100 %) | 101 % (inner 34.2 / outer 25.2 deg) | ✅ PASS |
| 5.1 | Brake system | hydraulic, acts on both rear wheels | single 180 mm disc on live axle, twin-piston caliper | ✅ PASS |
| 5.2 | Brake pedal | foot operated, steel/Al, travel stop | AISI 4130 pedal with stop | ✅ PASS |
| 5.3 | Brake over-travel switch | in series with kill switches | fitted ahead of pedal | ✅ PASS |
| 5.6 | Brake light | red, top centre of roll hoop | LED on hoop top centre | ✅ PASS |
| 6.2.1 | Engine | single cyl 4-stroke petrol <= 160 cc | Yamaha R15 V2 149.8 cc liquid cooled | ✅ PASS |
| 6.2.2 | Engine mounting tabs | >= 5 mm + damping | 6 mm tabs + rubber isolators | ✅ PASS |
| 6.2.3 | Fuel tank | <= 3 L, side-engine fuel area | 2.79 L behind seat (left) | ✅ PASS |
| 6.2.3 | Radiator | behind firewall | behind rear firewall, above axle | ✅ PASS |
| 6.2.4 | Exhaust outlet | behind driver, <= 650 mm high | X -186 mm, height 370 mm | ✅ PASS |
| 6.4 | Transmission | chain drive, RWD, scatter shield | #428 chain 14/34, Al scatter shield | ✅ PASS |
| 6.4.2 | Pedal layout | C-B-A left to right, throttle stop | clutch / brake / throttle | ✅ PASS |
| 6.5 | Kill switches | >= 2 (driver + both sides of hoop), red | 3 fitted | ✅ PASS |
| 6.9 | Fire extinguisher | 1 kg in cockpit, not on firewall | 1 kg ABC on left main rail | ✅ PASS |
| 6.10 | Fasteners | metal, grade 8.8, lock nuts | M8 8.8 + nyloc on all connectors | ✅ PASS |
| 7.1 | Bodywork | front (to steering wheel), L/R sides, rear | nose + 2 pods + rear panel | ✅ PASS |
| 7.1.2 | Floor close-out | >= 1 mm rigid, firewall to front | 2.0 mm aluminium | ✅ PASS |
| 9 | Number stickers | 6 in yellow: front, both sides, rear | 4 fitted | ✅ PASS |

## Interference check

* Part-to-part clashes (excluding intended welds/bolted contacts): **0**
* Driver (175 cm reference manikin) contacts: 0
* Front tyres swept lock-to-lock against frame/bumpers/body/steering: **0** contacts
* Whole steering linkage (column, wheel, pitman arm, tie rods, knuckles, hubs, rims, tyres) moved lock-to-lock (column -50.8 to +50.8 deg), exactly as the SolidWorks live-steering mates move it: **0** new contacts

## Files

* Assembly STEP: `S06_Perimeter_ASSEMBLY.step`
* Placement table (SolidWorks macro): `placements.csv`
* Live-steering mates (SolidWorks macro): `kinematics.csv`
* Bill of materials: `BOM.csv`
* Render iso: `renders/S06_iso.png`
* Render iso_rear: `renders/S06_iso_rear.png`
* Render top: `renders/S06_top.png`
* Render side: `renders/S06_side.png`
* Render side_driver: `renders/S06_side_driver.png`

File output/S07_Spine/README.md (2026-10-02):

# S07 - Spine

Central backbone tube with diagonal outriggers; F1-style narrow nose cone.

* Wheelbase **46.50 in** (1181.1 mm), front track 37.00 in, rear track 42.40 in
* Frame: `spine` - 18.5 m of 25.4 x 1.65 mm AISI 4130 chromoly, seamless (C 0.28-0.33 %) (~17.9 kg tube)
* Bumpers: front `chevron`, rear `straight`, side `bar`; body: nose `f1`, pods `slim`
* Steering: arm 155 mm at 15.50 deg, tie rods 270/389 mm (solver), lock inner 32.7 / outer 24.5 deg, R(outer front) 2.85 m, Ackermann 100 %

## Rule compliance (EKVC Season 4)

| Rule | Check | Requirement | This kart | Result |
|---|---|---|---|---|
| 1.1 | Wheelbase | <= 60 in (1524 mm) | 1181.1 mm (46.50 in) | ✅ PASS |
| 1.1 | Larger track (centre-to-centre) | <= 50 in (1270 mm) | 1077.0 mm (42.40 in) | ✅ PASS |
| 1.1 | Rear track outside-to-outside (conservative) | <= 50 in | 1257.3 mm (49.50 in) | ✅ PASS |
| 1.1 | Wheels not in line longitudinally | front track != rear track | F 940 / R 1077 mm | ✅ PASS |
| User | Front bumper to rear bumper (incl. foam) | < 65 in (1651 mm) | 1631.8 mm (64.24 in) | ✅ PASS |
| User | Overall length (any component) | < 65 in, nothing beyond bumpers | 1631.8 mm (64.24 in) | ✅ PASS |
| info | Overall width | (info) | 1296 mm (51.0 in) | ✅ PASS |
| 1.2 | Frame tube OD / wall | 1-2 in OD, >= 1.2 mm wall, seamless round | 25.4 x 1.65 mm, AISI 4130 chromoly, seamless (C 0.28-0.33 %) | ✅ PASS |
| 1.2 | Open tube end capped | >= 1 open end, capped | Silencer-stay end capped (6 mm plug) | ✅ PASS |
| 1.3 | Ground clearance (lowest non-tyre point) | 1-2 in (25.4-50.8 mm) | 35.0 mm (Firewall rear) | ✅ PASS |
| 1.4 | Hitch points | front + rear, not on bumper, yellow | 2 eyes on bulkhead tubes | ✅ PASS |
| 1.5 | Roll hoop height above helmet (175 cm driver) | >= 3 in (76.2 mm) | 115.0 mm | ✅ PASS |
| 1.5 | Roll hoop construction | one bent tube + 2 braces L/R | single bent tube, 2 rearward braces + cross bar | ✅ PASS |
| 1.6 | Front bumper ahead of front bulkhead | >= 4 in (101.6 mm) | 106.6 mm | ✅ PASS |
| 1.6 | Rear bumper behind rear bulkhead | >= 2 in (50.8 mm) | 56.8 mm | ✅ PASS |
| 1.6 | Bumpers cover tyres laterally | bumper reaches outer tyre edge | front +22 mm, rear +4 mm | ✅ PASS |
| 7.1.1 | No full-round bumper | side bumpers separate from front/rear | min X gap 332 mm | ✅ PASS |
| 1.6 | Bumper padding | foam pipe insulation | 12 mm closed-cell foam on all bumpers | ✅ PASS |
| 2.2 | Tyres | F 4.5x10.0-5, R 7.1x11.0-5 (D1) | as specified, 4 wheels | ✅ PASS |
| 3.1 | Seat | bucket seat, >= 4 mounts on primary members, lock nuts | GRP bucket, 4 mounts | ✅ PASS |
| 3.2 | Foot guard above toe | >= 3 in (76.2 mm) + anti-intrusion plate | 91.7 mm, 2 mm Al plate | ✅ PASS |
| 3.3 | Back angle | <= 30 deg from vertical | 20 deg | ✅ PASS |
| 3.5 | Firewall | >= 1.5 mm Al, no holes, nothing mounted | 1.5 mm 5052 side + rear panels | ✅ PASS |
| 4.1 | Steering mechanism | mechanical, no rack & pinion / by-wire | column + pitman arm + 2 tie rods (Ackermann) | ✅ PASS |
| 4.2 | Steering wheel | >= 10 in OD full circle | 280 mm round | ✅ PASS |
| 4.3 | Steering stops | positive stops on chassis | 2 adjustable stops on column lower bracket | ✅ PASS |
| 4.4 | Turning radius (outer front wheel) | <= 3 m | L 2.85 m / R 2.80 m | ✅ PASS |
| info | Ackermann at lock | (design target ~100 %) | 100 % (inner 32.7 / outer 24.5 deg) | ✅ PASS |
| 5.1 | Brake system | hydraulic, acts on both rear wheels | single 180 mm disc on live axle, twin-piston caliper | ✅ PASS |
| 5.2 | Brake pedal | foot operated, steel/Al, travel stop | AISI 4130 pedal with stop | ✅ PASS |
| 5.3 | Brake over-travel switch | in series with kill switches | fitted ahead of pedal | ✅ PASS |
| 5.6 | Brake light | red, top centre of roll hoop | LED on hoop top centre | ✅ PASS |
| 6.2.1 | Engine | single cyl 4-stroke petrol <= 160 cc | Yamaha R15 V2 149.8 cc liquid cooled | ✅ PASS |
| 6.2.2 | Engine mounting tabs | >= 5 mm + damping | 6 mm tabs + rubber isolators | ✅ PASS |
| 6.2.3 | Fuel tank | <= 3 L, side-engine fuel area | 2.79 L behind seat (left) | ✅ PASS |
| 6.2.3 | Radiator | behind firewall | behind rear firewall, above axle | ✅ PASS |
| 6.2.4 | Exhaust outlet | behind driver, <= 650 mm high | X -186 mm, height 370 mm | ✅ PASS |
| 6.4 | Transmission | chain drive, RWD, scatter shield | #428 chain 14/34, Al scatter shield | ✅ PASS |
| 6.4.2 | Pedal layout | C-B-A left to right, throttle stop | clutch / brake / throttle | ✅ PASS |
| 6.5 | Kill switches | >= 2 (driver + both sides of hoop), red | 3 fitted | ✅ PASS |
| 6.9 | Fire extinguisher | 1 kg in cockpit, not on firewall | 1 kg ABC on left main rail | ✅ PASS |
| 6.10 | Fasteners | metal, grade 8.8, lock nuts | M8 8.8 + nyloc on all connectors | ✅ PASS |
| 7.1 | Bodywork | front (to steering wheel), L/R sides, rear | nose + 2 pods + rear panel | ✅ PASS |
| 7.1.2 | Floor close-out | >= 1 mm rigid, firewall to front | 2.0 mm aluminium | ✅ PASS |
| 9 | Number stickers | 6 in yellow: front, both sides, rear | 4 fitted | ✅ PASS |

## Interference check

* Part-to-part clashes (excluding intended welds/bolted contacts): **0**
* Driver (175 cm reference manikin) contacts: 0
* Front tyres swept lock-to-lock against frame/bumpers/body/steering: **0** contacts
* Whole steering linkage (column, wheel, pitman arm, tie rods, knuckles, hubs, rims, tyres) moved lock-to-lock (column -50.8 to +48.8 deg), exactly as the SolidWorks live-steering mates move it: **0** new contacts

## Files

* Assembly STEP: `S07_Spine_ASSEMBLY.step`
* Placement table (SolidWorks macro): `placements.csv`
* Live-steering mates (SolidWorks macro): `kinematics.csv`
* Bill of materials: `BOM.csv`
* Render iso: `renders/S07_iso.png`
* Render iso_rear: `renders/S07_iso_rear.png`
* Render top: `renders/S07_top.png`
* Render side: `renders/S07_side.png`
* Render side_driver: `renders/S07_side_driver.png`

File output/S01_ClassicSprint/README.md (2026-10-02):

# S01 - Classic Sprint

Straight parallel main rails, three-cross ladder, square nose. The reference build.

* Wheelbase **47.00 in** (1193.8 mm), front track 37.00 in, rear track 42.80 in
* Frame: `ladder3` - 17.8 m of 25.4 x 1.65 mm AISI 4130 chromoly, seamless (C 0.28-0.33 %) (~17.2 kg tube)
* Bumpers: front `straight`, rear `straight`, side `bar`; body: nose `box`, pods `box`
* Steering: arm 155 mm at 15.00 deg, tie rods 271/391 mm (solver), lock inner 33.8 / outer 25.2 deg, R(outer front) 2.81 m, Ackermann 100 %

## Rule compliance (EKVC Season 4)

| Rule | Check | Requirement | This kart | Result |
|---|---|---|---|---|
| 1.1 | Wheelbase | <= 60 in (1524 mm) | 1193.8 mm (47.00 in) | ✅ PASS |
| 1.1 | Larger track (centre-to-centre) | <= 50 in (1270 mm) | 1087.1 mm (42.80 in) | ✅ PASS |
| 1.1 | Rear track outside-to-outside (conservative) | <= 50 in | 1267.5 mm (49.90 in) | ✅ PASS |
| 1.1 | Wheels not in line longitudinally | front track != rear track | F 940 / R 1087 mm | ✅ PASS |
| User | Front bumper to rear bumper (incl. foam) | < 65 in (1651 mm) | 1635.9 mm (64.41 in) | ✅ PASS |
| User | Overall length (any component) | < 65 in, nothing beyond bumpers | 1635.9 mm (64.41 in) | ✅ PASS |
| info | Overall width | (info) | 1310 mm (51.6 in) | ✅ PASS |
| 1.2 | Frame tube OD / wall | 1-2 in OD, >= 1.2 mm wall, seamless round | 25.4 x 1.65 mm, AISI 4130 chromoly, seamless (C 0.28-0.33 %) | ✅ PASS |
| 1.2 | Open tube end capped | >= 1 open end, capped | Silencer-stay end capped (6 mm plug) | ✅ PASS |
| 1.3 | Ground clearance (lowest non-tyre point) | 1-2 in (25.4-50.8 mm) | 35.0 mm (Firewall rear) | ✅ PASS |
| 1.4 | Hitch points | front + rear, not on bumper, yellow | 2 eyes on bulkhead tubes | ✅ PASS |
| 1.5 | Roll hoop height above helmet (175 cm driver) | >= 3 in (76.2 mm) | 115.0 mm | ✅ PASS |
| 1.5 | Roll hoop construction | one bent tube + 2 braces L/R | single bent tube, 2 rearward braces + cross bar | ✅ PASS |
| 1.6 | Front bumper ahead of front bulkhead | >= 4 in (101.6 mm) | 114.7 mm | ✅ PASS |
| 1.6 | Rear bumper behind rear bulkhead | >= 2 in (50.8 mm) | 56.8 mm | ✅ PASS |
| 1.6 | Bumpers cover tyres laterally | bumper reaches outer tyre edge | front +22 mm, rear +4 mm | ✅ PASS |
| 7.1.1 | No full-round bumper | side bumpers separate from front/rear | min X gap 315 mm | ✅ PASS |
| 1.6 | Bumper padding | foam pipe insulation | 12 mm closed-cell foam on all bumpers | ✅ PASS |
| 2.2 | Tyres | F 4.5x10.0-5, R 7.1x11.0-5 (D1) | as specified, 4 wheels | ✅ PASS |
| 3.1 | Seat | bucket seat, >= 4 mounts on primary members, lock nuts | GRP bucket, 4 mounts | ✅ PASS |
| 3.2 | Foot guard above toe | >= 3 in (76.2 mm) + anti-intrusion plate | 91.7 mm, 2 mm Al plate | ✅ PASS |
| 3.3 | Back angle | <= 30 deg from vertical | 20 deg | ✅ PASS |
| 3.5 | Firewall | >= 1.5 mm Al, no holes, nothing mounted | 1.5 mm 5052 side + rear panels | ✅ PASS |
| 4.1 | Steering mechanism | mechanical, no rack & pinion / by-wire | column + pitman arm + 2 tie rods (Ackermann) | ✅ PASS |
| 4.2 | Steering wheel | >= 10 in OD full circle | 280 mm round | ✅ PASS |
| 4.3 | Steering stops | positive stops on chassis | 2 adjustable stops on column lower bracket | ✅ PASS |
| 4.4 | Turning radius (outer front wheel) | <= 3 m | L 2.81 m / R 2.83 m | ✅ PASS |
| info | Ackermann at lock | (design target ~100 %) | 100 % (inner 33.8 / outer 25.2 deg) | ✅ PASS |
| 5.1 | Brake system | hydraulic, acts on both rear wheels | single 180 mm disc on live axle, twin-piston caliper | ✅ PASS |
| 5.2 | Brake pedal | foot operated, steel/Al, travel stop | AISI 4130 pedal with stop | ✅ PASS |
| 5.3 | Brake over-travel switch | in series with kill switches | fitted ahead of pedal | ✅ PASS |
| 5.6 | Brake light | red, top centre of roll hoop | LED on hoop top centre | ✅ PASS |
| 6.2.1 | Engine | single cyl 4-stroke petrol <= 160 cc | Yamaha R15 V2 149.8 cc liquid cooled | ✅ PASS |
| 6.2.2 | Engine mounting tabs | >= 5 mm + damping | 6 mm tabs + rubber isolators | ✅ PASS |
| 6.2.3 | Fuel tank | <= 3 L, side-engine fuel area | 2.79 L behind seat (left) | ✅ PASS |
| 6.2.3 | Radiator | behind firewall | behind rear firewall, above axle | ✅ PASS |
| 6.2.4 | Exhaust outlet | behind driver, <= 650 mm high | X -186 mm, height 370 mm | ✅ PASS |
| 6.4 | Transmission | chain drive, RWD, scatter shield | #428 chain 14/34, Al scatter shield | ✅ PASS |
| 6.4.2 | Pedal layout | C-B-A left to right, throttle stop | clutch / brake / throttle | ✅ PASS |
| 6.5 | Kill switches | >= 2 (driver + both sides of hoop), red | 3 fitted | ✅ PASS |
| 6.9 | Fire extinguisher | 1 kg in cockpit, not on firewall | 1 kg ABC on left main rail | ✅ PASS |
| 6.10 | Fasteners | metal, grade 8.8, lock nuts | M8 8.8 + nyloc on all connectors | ✅ PASS |
| 7.1 | Bodywork | front (to steering wheel), L/R sides, rear | nose + 2 pods + rear panel | ✅ PASS |
| 7.1.2 | Floor close-out | >= 1 mm rigid, firewall to front | 2.0 mm aluminium | ✅ PASS |
| 9 | Number stickers | 6 in yellow: front, both sides, rear | 4 fitted | ✅ PASS |

## Interference check

* Part-to-part clashes (excluding intended welds/bolted contacts): **0**
* Driver (175 cm reference manikin) contacts: 0
* Front tyres swept lock-to-lock against frame/bumpers/body/steering: **0** contacts
* Whole steering linkage (column, wheel, pitman arm, tie rods, knuckles, hubs, rims, tyres) moved lock-to-lock (column -50.8 to +50.8 deg), exactly as the SolidWorks live-steering mates move it: **0** new contacts

## Files

* Assembly STEP: `S01_ClassicSprint_ASSEMBLY.step`
* Placement table (SolidWorks macro): `placements.csv`
* Live-steering mates (SolidWorks macro): `kinematics.csv`
* Bill of materials: `BOM.csv`
* Render iso: `renders/S01_iso.png`
* Render iso_rear: `renders/S01_iso_rear.png`
* Render top: `renders/S01_top.png`
* Render side: `renders/S01_side.png`
* Render side_driver: `renders/S01_side_driver.png`

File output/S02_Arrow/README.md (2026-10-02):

# S02 - Arrow

Main rails taper hard into a narrow nose; V-chevron front bumper, arched rear bumper.

* Wheelbase **46.00 in** (1168.4 mm), front track 36.50 in, rear track 42.60 in
* Frame: `taper` - 18.3 m of 25.4 x 1.65 mm AISI 4130 chromoly, seamless (C 0.28-0.33 %) (~17.7 kg tube)
* Bumpers: front `chevron`, rear `arc`, side `bar_kick`; body: nose `arrow`, pods `wedge`
* Steering: arm 155 mm at 15.50 deg, tie rods 263/383 mm (solver), lock inner 32.7 / outer 24.5 deg, R(outer front) 2.82 m, Ackermann 99 %

## Rule compliance (EKVC Season 4)

| Rule | Check | Requirement | This kart | Result |
|---|---|---|---|---|
| 1.1 | Wheelbase | <= 60 in (1524 mm) | 1168.4 mm (46.00 in) | ✅ PASS |
| 1.1 | Larger track (centre-to-centre) | <= 50 in (1270 mm) | 1082.0 mm (42.60 in) | ✅ PASS |
| 1.1 | Rear track outside-to-outside (conservative) | <= 50 in | 1262.4 mm (49.70 in) | ✅ PASS |
| 1.1 | Wheels not in line longitudinally | front track != rear track | F 927 / R 1082 mm | ✅ PASS |
| User | Front bumper to rear bumper (incl. foam) | < 65 in (1651 mm) | 1637.8 mm (64.48 in) | ✅ PASS |
| User | Overall length (any component) | < 65 in, nothing beyond bumpers | 1637.8 mm (64.48 in) | ✅ PASS |
| info | Overall width | (info) | 1309 mm (51.5 in) | ✅ PASS |
| 1.2 | Frame tube OD / wall | 1-2 in OD, >= 1.2 mm wall, seamless round | 25.4 x 1.65 mm, AISI 4130 chromoly, seamless (C 0.28-0.33 %) | ✅ PASS |
| 1.2 | Open tube end capped | >= 1 open end, capped | Silencer-stay end capped (6 mm plug) | ✅ PASS |
| 1.3 | Ground clearance (lowest non-tyre point) | 1-2 in (25.4-50.8 mm) | 35.0 mm (Firewall rear) | ✅ PASS |
| 1.4 | Hitch points | front + rear, not on bumper, yellow | 2 eyes on bulkhead tubes | ✅ PASS |
| 1.5 | Roll hoop height above helmet (175 cm driver) | >= 3 in (76.2 mm) | 115.0 mm | ✅ PASS |
| 1.5 | Roll hoop construction | one bent tube + 2 braces L/R | single bent tube, 2 rearward braces + cross bar | ✅ PASS |
| 1.6 | Front bumper ahead of front bulkhead | >= 4 in (101.6 mm) | 106.6 mm | ✅ PASS |
| 1.6 | Rear bumper behind rear bulkhead | >= 2 in (50.8 mm) | 56.8 mm | ✅ PASS |
| 1.6 | Bumpers cover tyres laterally | bumper reaches outer tyre edge | front +22 mm, rear +4 mm | ✅ PASS |
| 7.1.1 | No full-round bumper | side bumpers separate from front/rear | min X gap 335 mm | ✅ PASS |
| 1.6 | Bumper padding | foam pipe insulation | 12 mm closed-cell foam on all bumpers | ✅ PASS |
| 2.2 | Tyres | F 4.5x10.0-5, R 7.1x11.0-5 (D1) | as specified, 4 wheels | ✅ PASS |
| 3.1 | Seat | bucket seat, >= 4 mounts on primary members, lock nuts | GRP bucket, 4 mounts | ✅ PASS |
| 3.2 | Foot guard above toe | >= 3 in (76.2 mm) + anti-intrusion plate | 91.7 mm, 2 mm Al plate | ✅ PASS |
| 3.3 | Back angle | <= 30 deg from vertical | 20 deg | ✅ PASS |
| 3.5 | Firewall | >= 1.5 mm Al, no holes, nothing mounted | 1.5 mm 5052 side + rear panels | ✅ PASS |
| 4.1 | Steering mechanism | mechanical, no rack & pinion / by-wire | column + pitman arm + 2 tie rods (Ackermann) | ✅ PASS |
| 4.2 | Steering wheel | >= 10 in OD full circle | 280 mm round | ✅ PASS |
| 4.3 | Steering stops | positive stops on chassis | 2 adjustable stops on column lower bracket | ✅ PASS |
| 4.4 | Turning radius (outer front wheel) | <= 3 m | L 2.82 m / R 2.83 m | ✅ PASS |
| info | Ackermann at lock | (design target ~100 %) | 99 % (inner 32.7 / outer 24.5 deg) | ✅ PASS |
| 5.1 | Brake system | hydraulic, acts on both rear wheels | single 180 mm disc on live axle, twin-piston caliper | ✅ PASS |
| 5.2 | Brake pedal | foot operated, steel/Al, travel stop | AISI 4130 pedal with stop | ✅ PASS |
| 5.3 | Brake over-travel switch | in series with kill switches | fitted ahead of pedal | ✅ PASS |
| 5.6 | Brake light | red, top centre of roll hoop | LED on hoop top centre | ✅ PASS |
| 6.2.1 | Engine | single cyl 4-stroke petrol <= 160 cc | Yamaha R15 V2 149.8 cc liquid cooled | ✅ PASS |
| 6.2.2 | Engine mounting tabs | >= 5 mm + damping | 6 mm tabs + rubber isolators | ✅ PASS |
| 6.2.3 | Fuel tank | <= 3 L, side-engine fuel area | 2.79 L behind seat (left) | ✅ PASS |
| 6.2.3 | Radiator | behind firewall | behind rear firewall, above axle | ✅ PASS |
| 6.2.4 | Exhaust outlet | behind driver, <= 650 mm high | X -186 mm, height 370 mm | ✅ PASS |
| 6.4 | Transmission | chain drive, RWD, scatter shield | #428 chain 14/34, Al scatter shield | ✅ PASS |
| 6.4.2 | Pedal layout | C-B-A left to right, throttle stop | clutch / brake / throttle | ✅ PASS |
| 6.5 | Kill switches | >= 2 (driver + both sides of hoop), red | 3 fitted | ✅ PASS |
| 6.9 | Fire extinguisher | 1 kg in cockpit, not on firewall | 1 kg ABC on left main rail | ✅ PASS |
| 6.10 | Fasteners | metal, grade 8.8, lock nuts | M8 8.8 + nyloc on all connectors | ✅ PASS |
| 7.1 | Bodywork | front (to steering wheel), L/R sides, rear | nose + 2 pods + rear panel | ✅ PASS |
| 7.1.2 | Floor close-out | >= 1 mm rigid, firewall to front | 2.0 mm aluminium | ✅ PASS |
| 9 | Number stickers | 6 in yellow: front, both sides, rear | 4 fitted | ✅ PASS |

## Interference check

* Part-to-part clashes (excluding intended welds/bolted contacts): **0**
* Driver (175 cm reference manikin) contacts: 0
* Front tyres swept lock-to-lock against frame/bumpers/body/steering: **0** contacts
* Whole steering linkage (column, wheel, pitman arm, tie rods, knuckles, hubs, rims, tyres) moved lock-to-lock (column -48.8 to +48.8 deg), exactly as the SolidWorks live-steering mates move it: **0** new contacts

## Files

* Assembly STEP: `S02_Arrow_ASSEMBLY.step`
* Placement table (SolidWorks macro): `placements.csv`
* Live-steering mates (SolidWorks macro): `kinematics.csv`
* Bill of materials: `BOM.csv`
* Render iso: `renders/S02_iso.png`
* Render iso_rear: `renders/S02_iso_rear.png`
* Render top: `renders/S02_top.png`
* Render side: `renders/S02_side.png`
* Render side_driver: `renders/S02_side_driver.png`

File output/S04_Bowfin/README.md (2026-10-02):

# S04 - Bowfin

Main rails bowed outward around the seat with an X under the floor; curved bumpers all round.

* Wheelbase **46.00 in** (1168.4 mm), front track 37.50 in, rear track 42.60 in
* Frame: `bowed` - 18.3 m of 25.4 x 1.65 mm AISI 4130 chromoly, seamless (C 0.28-0.33 %) (~17.7 kg tube)
* Bumpers: front `arc`, rear `arc`, side `arc`; body: nose `round`, pods `round`
* Steering: arm 155 mm at 16.25 deg, tie rods 274/394 mm (solver), lock inner 33.1 / outer 24.5 deg, R(outer front) 2.82 m, Ackermann 100 %

## Rule compliance (EKVC Season 4)

| Rule | Check | Requirement | This kart | Result |
|---|---|---|---|---|
| 1.1 | Wheelbase | <= 60 in (1524 mm) | 1168.4 mm (46.00 in) | ✅ PASS |
| 1.1 | Larger track (centre-to-centre) | <= 50 in (1270 mm) | 1082.0 mm (42.60 in) | ✅ PASS |
| 1.1 | Rear track outside-to-outside (conservative) | <= 50 in | 1262.4 mm (49.70 in) | ✅ PASS |
| 1.1 | Wheels not in line longitudinally | front track != rear track | F 952 / R 1082 mm | ✅ PASS |
| User | Front bumper to rear bumper (incl. foam) | < 65 in (1651 mm) | 1636.8 mm (64.44 in) | ✅ PASS |
| User | Overall length (any component) | < 65 in, nothing beyond bumpers | 1636.8 mm (64.44 in) | ✅ PASS |
| info | Overall width | (info) | 1344 mm (52.9 in) | ✅ PASS |
| 1.2 | Frame tube OD / wall | 1-2 in OD, >= 1.2 mm wall, seamless round | 25.4 x 1.65 mm, AISI 4130 chromoly, seamless (C 0.28-0.33 %) | ✅ PASS |
| 1.2 | Open tube end capped | >= 1 open end, capped | Silencer-stay end capped (6 mm plug) | ✅ PASS |
| 1.3 | Ground clearance (lowest non-tyre point) | 1-2 in (25.4-50.8 mm) | 35.0 mm (Firewall rear) | ✅ PASS |
| 1.4 | Hitch points | front + rear, not on bumper, yellow | 2 eyes on bulkhead tubes | ✅ PASS |
| 1.5 | Roll hoop height above helmet (175 cm driver) | >= 3 in (76.2 mm) | 115.0 mm | ✅ PASS |
| 1.5 | Roll hoop construction | one bent tube + 2 braces L/R | single bent tube, 2 rearward braces + cross bar | ✅ PASS |
| 1.6 | Front bumper ahead of front bulkhead | >= 4 in (101.6 mm) | 106.6 mm | ✅ PASS |
| 1.6 | Rear bumper behind rear bulkhead | >= 2 in (50.8 mm) | 56.8 mm | ✅ PASS |
| 1.6 | Bumpers cover tyres laterally | bumper reaches outer tyre edge | front +22 mm, rear +4 mm | ✅ PASS |
| 7.1.1 | No full-round bumper | side bumpers separate from front/rear | min X gap 338 mm | ✅ PASS |
| 1.6 | Bumper padding | foam pipe insulation | 12 mm closed-cell foam on all bumpers | ✅ PASS |
| 2.2 | Tyres | F 4.5x10.0-5, R 7.1x11.0-5 (D1) | as specified, 4 wheels | ✅ PASS |
| 3.1 | Seat | bucket seat, >= 4 mounts on primary members, lock nuts | GRP bucket, 4 mounts | ✅ PASS |
| 3.2 | Foot guard above toe | >= 3 in (76.2 mm) + anti-intrusion plate | 91.7 mm, 2 mm Al plate | ✅ PASS |
| 3.3 | Back angle | <= 30 deg from vertical | 20 deg | ✅ PASS |
| 3.5 | Firewall | >= 1.5 mm Al, no holes, nothing mounted | 1.5 mm 5052 side + rear panels | ✅ PASS |
| 4.1 | Steering mechanism | mechanical, no rack & pinion / by-wire | column + pitman arm + 2 tie rods (Ackermann) | ✅ PASS |
| 4.2 | Steering wheel | >= 10 in OD full circle | 280 mm round | ✅ PASS |
| 4.3 | Steering stops | positive stops on chassis | 2 adjustable stops on column lower bracket | ✅ PASS |
| 4.4 | Turning radius (outer front wheel) | <= 3 m | L 2.82 m / R 2.83 m | ✅ PASS |
| info | Ackermann at lock | (design target ~100 %) | 100 % (inner 33.1 / outer 24.5 deg) | ✅ PASS |
| 5.1 | Brake system | hydraulic, acts on both rear wheels | single 180 mm disc on live axle, twin-piston caliper | ✅ PASS |
| 5.2 | Brake pedal | foot operated, steel/Al, travel stop | AISI 4130 pedal with stop | ✅ PASS |
| 5.3 | Brake over-travel switch | in series with kill switches | fitted ahead of pedal | ✅ PASS |
| 5.6 | Brake light | red, top centre of roll hoop | LED on hoop top centre | ✅ PASS |
| 6.2.1 | Engine | single cyl 4-stroke petrol <= 160 cc | Yamaha R15 V2 149.8 cc liquid cooled | ✅ PASS |
| 6.2.2 | Engine mounting tabs | >= 5 mm + damping | 6 mm tabs + rubber isolators | ✅ PASS |
| 6.2.3 | Fuel tank | <= 3 L, side-engine fuel area | 2.79 L behind seat (left) | ✅ PASS |
| 6.2.3 | Radiator | behind firewall | behind rear firewall, above axle | ✅ PASS |
| 6.2.4 | Exhaust outlet | behind driver, <= 650 mm high | X -186 mm, height 370 mm | ✅ PASS |
| 6.4 | Transmission | chain drive, RWD, scatter shield | #428 chain 14/34, Al scatter shield | ✅ PASS |
| 6.4.2 | Pedal layout | C-B-A left to right, throttle stop | clutch / brake / throttle | ✅ PASS |
| 6.5 | Kill switches | >= 2 (driver + both sides of hoop), red | 3 fitted | ✅ PASS |
| 6.9 | Fire extinguisher | 1 kg in cockpit, not on firewall | 1 kg ABC on left main rail | ✅ PASS |
| 6.10 | Fasteners | metal, grade 8.8, lock nuts | M8 8.8 + nyloc on all connectors | ✅ PASS |
| 7.1 | Bodywork | front (to steering wheel), L/R sides, rear | nose + 2 pods + rear panel | ✅ PASS |
| 7.1.2 | Floor close-out | >= 1 mm rigid, firewall to front | 2.0 mm aluminium | ✅ PASS |
| 9 | Number stickers | 6 in yellow: front, both sides, rear | 4 fitted | ✅ PASS |

## Interference check

* Part-to-part clashes (excluding intended welds/bolted contacts): **0**
* Driver (175 cm reference manikin) contacts: 0
* Front tyres swept lock-to-lock against frame/bumpers/body/steering: **0** contacts
* Whole steering linkage (column, wheel, pitman arm, tie rods, knuckles, hubs, rims, tyres) moved lock-to-lock (column -48.8 to +48.8 deg), exactly as the SolidWorks live-steering mates move it: **0** new contacts

## Files

* Assembly STEP: `S04_Bowfin_ASSEMBLY.step`
* Placement table (SolidWorks macro): `placements.csv`
* Live-steering mates (SolidWorks macro): `kinematics.csv`
* Bill of materials: `BOM.csv`
* Render iso: `renders/S04_iso.png`
* Render iso_rear: `renders/S04_iso_rear.png`
* Render top: `renders/S04_top.png`
* Render side: `renders/S04_side.png`
* Render side_driver: `renders/S04_side_driver.png`

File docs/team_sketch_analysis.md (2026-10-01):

# Team sketch analysis (`mutusami_sterring.SLDPRT`)

The uploaded file is internally named **`therika2.SLDPRT`** (saved 01-Aug-2026 by PUBESHVARAN S G,
SOLIDWORKS units = inches). It contains no solid bodies - only one 2D layout sketch (`Sketch2`)
on the Top plane. Preview: `team_sketch_preview.png`.

Dimensions decoded from the sketch (inches):

| Dim | Value | Meaning (from the sketch geometry) |
|---|---|---|
| D1 | 51.00 | wheelbase (front axle x = -28.147, rear axle x = 22.853) |
| D2 | 37.00 | front track, centre-to-centre |
| D3 | 43.00 | rear track, centre-to-centre |
| D4 / D5 | 4.50 / 10.00 | front tyre width / diameter |
| D6 / D7 | 7.10 / 11.00 | rear tyre width / diameter |
| D12 / D16 | 14.98 / 28.89 | king-pin position (half-spacing 14.98 -> 3.52 in scrub from wheel centre) |
| D15, D22 | 110 deg | steering-arm angle at each knuckle |
| D25 | 123.56 deg | Ackermann construction angle |
| D18 | 32.00 | main frame rail spacing |
| D9 | 52.00 | front bumper width |
| D10 | 73.31 | front bumper to rear bumper |

## What was kept / changed for the 10 styles

* Tyre sizes and king-pin scrub (3.52 in) - **kept**.
* Front track 37 in - kept for S01/S03/S07, varied 36-38 in on the other styles.
* Rear track 43 in -> **42.0-42.8 in**, so the rear stays under 50 in even measured over the tyres
  (43 + 7.1 = 50.1 in would be 0.1 in over if measured outside-to-outside).
* Wheelbase 51 in -> **46-47 in**: with 51 in the tyres alone span 61.5 in, leaving ~1.7 in per end for
  bumpers under the 65 in overall limit (and the sketch measured 73.3 in).
* The 110 deg arm angle (100 % Ackermann line to the rear-axle centre) produced ~145 % Ackermann
  with a real pitman linkage, so the arm angle is now **solved numerically per style** (6.5-8.5 deg
  with 155 mm arms) for ~100 % Ackermann at full lock and an outer-wheel radius of ~2.8 m.

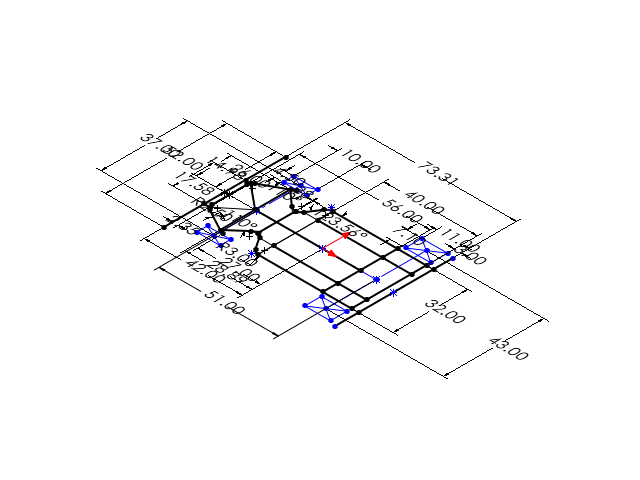
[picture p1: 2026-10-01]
docs/team_sketch_preview.png

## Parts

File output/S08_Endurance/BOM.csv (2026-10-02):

Part number | Name | Qty | Group | Material | Notes | STEP file (convert to .SLDPRT)
C-BOD-01 | Kart number sticker 6in yellow (X) | 2 | body | Vinyl, yellow background, black numerals | Rule 9 - 6 in circular, yellow/black | ../common/parts/C-BOD-01_Kart_number_sticker_6in_yellow_X.step
C-BOD-02 | Kart number sticker 6in yellow (Z) | 2 | body | Vinyl, yellow background, black numerals | Rule 9 - 6 in circular, yellow/black | ../common/parts/C-BOD-02_Kart_number_sticker_6in_yellow_Z.step
S08-BOD-01 | Nose front panel round | 1 | body | GRP / ABS 3 mm | Covers front bumper to steering wheel (rule 7.1); metal fasteners to foot guard & front bumper | parts/S08-BOD-01_Nose_front_panel_round.step
S08-BOD-02 | Side pod left full | 1 | body | GRP / ABS 3 mm | Left/right side bodywork on side bumper (rule 7.1.1) | parts/S08-BOD-02_Side_pod_left_full.step
S08-BOD-03 | Side pod right full | 1 | body | GRP / ABS 3 mm | Left/right side bodywork on side bumper (rule 7.1.1) | parts/S08-BOD-03_Side_pod_right_full.step
S08-BOD-04 | Rear panel | 1 | body | GRP / ABS 3 mm | Rear bodywork behind rear tyres, on rear bumper (rule 7.1.1) | parts/S08-BOD-04_Rear_panel.step
S08-BOD-10 | Floor close-out pan 2mm | 1 | body | Aluminium 5052-H32 2 mm | 0.523 m2, gaps < 3 mm, bolted M6 every 150 mm (rule 7.1.2) | parts/S08-BOD-10_Floor_close_out_pan_2mm.step
C-BRK-01 | Brake disc 180x5 | 1 | brakes | Stainless 420, hardened | Single rear disc on live axle, locks both rear wheels (rule 5.1) | ../common/parts/C-BRK-01_Brake_disc_180x5.step
C-BRK-02 | Disc carrier 40mm keyed | 1 | brakes | Al 7075-T6 | Keyed clamp hub, 4x M8 PCD 70 | ../common/parts/C-BRK-02_Disc_carrier_40mm_keyed.step
C-BRK-03 | Brake caliper twin piston | 1 | brakes | Cast aluminium (bought out) | Hydraulic caliper, DOT4 | ../common/parts/C-BRK-03_Brake_caliper_twin_piston.step
C-BRK-04 | Caliper mounting bracket 6mm | 1 | brakes | AISI 4130 plate 6 mm | Welded to rear bulkhead | ../common/parts/C-BRK-04_Caliper_mounting_bracket_6mm.step
C-BRK-05 | Brake master cylinder 5/8in with reservoir | 1 | brakes | Bought out, DOT4 | Own fluid reservoir (rule 5.1); pushed by brake pedal upper lever | ../common/parts/C-BRK-05_Brake_master_cylinder_5_8in_with_reservoir.step
C-BRK-06 | Master cylinder bracket | 1 | brakes | AISI 4130 plate 6 mm | Welded to foot-guard top bar | ../common/parts/C-BRK-06_Master_cylinder_bracket.step
C-BRK-07 | Brake over-travel switch | 1 | brakes | Bought out, NC micro-switch IP67 | Hit by the brake pedal arm only on over-travel; in series with kill switches (rule 5.3) | ../common/parts/C-BRK-07_Brake_over_travel_switch.step
S08-BRK-08 | Brake line 3/16in braided | 1 | brakes | Stainless braided PTFE hose | Metal P-clips every 300 mm; routed outboard of left main rail (rule 5.4) | parts/S08-BRK-08_Brake_line_3_16in_braided.step
S08-BMP-01 | Front bumper | 1 | bumpers | AISI 4130 chromoly, seamless (C 0.28-0.33 %) - single seamless tube | Single bent tube, U; >= 4 in ahead of front bulkhead | parts/S08-BMP-01_Front_bumper.step
S08-BMP-02 | Rear bumper | 1 | bumpers | AISI 4130 chromoly, seamless (C 0.28-0.33 %) - single seamless tube | Single bent tube, U; >= 2 in behind rear bulkhead | parts/S08-BMP-02_Rear_bumper.step
S08-BMP-03 | Side bumper left | 1 | bumpers | AISI 4130 chromoly, seamless (C 0.28-0.33 %) - single seamless tube | Single bent tube (double); separate from front/rear (no full-round bumper) | parts/S08-BMP-03_Side_bumper_left.step
S08-BMP-04 | Side bumper right | 1 | bumpers | AISI 4130 chromoly, seamless (C 0.28-0.33 %) - single seamless tube | Single bent tube (double); separate from front/rear (no full-round bumper) | parts/S08-BMP-04_Side_bumper_right.step
S08-BMP-05 | Front bumper foam | 1 | bumpers | Closed-cell foam pipe insulation 12 mm | Rule 1.6 - padding over bumper | parts/S08-BMP-05_Front_bumper_foam.step
S08-BMP-06 | Rear bumper foam | 1 | bumpers | Closed-cell foam pipe insulation 12 mm | Rule 1.6 - padding over bumper | parts/S08-BMP-06_Rear_bumper_foam.step
S08-BMP-07 | Side bumper left foam | 1 | bumpers | Closed-cell foam pipe insulation 12 mm | Rule 1.6 - padding over bumper | parts/S08-BMP-07_Side_bumper_left_foam.step
S08-BMP-08 | Side bumper right foam | 1 | bumpers | Closed-cell foam pipe insulation 12 mm | Rule 1.6 - padding over bumper | parts/S08-BMP-08_Side_bumper_right_foam.step
S08-CON-01A | Front connector chassis tab | 1 | connectors | AISI 4130 plate 6 mm | Welded to chassis; 2x M8 8.8 + nyloc to bumper tab | parts/S08-CON-01A_Front_connector_chassis_tab.step
S08-CON-01B | Front connector bumper tab | 1 | connectors | AISI 4130 plate 6 mm | Welded to bumper tube; bolts to chassis tab | parts/S08-CON-01B_Front_connector_bumper_tab.step
S08-CON-02A | Front connector chassis tab | 1 | connectors | AISI 4130 plate 6 mm | Welded to chassis; 2x M8 8.8 + nyloc to bumper tab | parts/S08-CON-02A_Front_connector_chassis_tab.step
S08-CON-02B | Front connector bumper tab | 1 | connectors | AISI 4130 plate 6 mm | Welded to bumper tube; bolts to chassis tab | parts/S08-CON-02B_Front_connector_bumper_tab.step
S08-CON-03A | Rear connector chassis tab | 1 | connectors | AISI 4130 plate 6 mm | Welded to chassis; 2x M8 8.8 + nyloc to bumper tab | parts/S08-CON-03A_Rear_connector_chassis_tab.step
S08-CON-03B | Rear connector bumper tab | 1 | connectors | AISI 4130 plate 6 mm | Welded to bumper tube; bolts to chassis tab | parts/S08-CON-03B_Rear_connector_bumper_tab.step
S08-CON-04A | Rear connector chassis tab | 1 | connectors | AISI 4130 plate 6 mm | Welded to chassis; 2x M8 8.8 + nyloc to bumper tab | parts/S08-CON-04A_Rear_connector_chassis_tab.step
S08-CON-04B | Rear connector bumper tab | 1 | connectors | AISI 4130 plate 6 mm | Welded to bumper tube; bolts to chassis tab | parts/S08-CON-04B_Rear_connector_bumper_tab.step
S08-CON-05A | Side L connector chassis tab | 1 | connectors | AISI 4130 plate 6 mm | Welded to chassis; 2x M8 8.8 + nyloc to bumper tab | parts/S08-CON-05A_Side_L_connector_chassis_tab.step
S08-CON-05B | Side L connector bumper tab | 1 | connectors | AISI 4130 plate 6 mm | Welded to bumper tube; bolts to chassis tab | parts/S08-CON-05B_Side_L_connector_bumper_tab.step
S08-CON-06A | Side L connector chassis tab | 1 | connectors | AISI 4130 plate 6 mm | Welded to chassis; 2x M8 8.8 + nyloc to bumper tab | parts/S08-CON-06A_Side_L_connector_chassis_tab.step
S08-CON-06B | Side L connector bumper tab | 1 | connectors | AISI 4130 plate 6 mm | Welded to bumper tube; bolts to chassis tab | parts/S08-CON-06B_Side_L_connector_bumper_tab.step
S08-CON-07A | Side R connector chassis tab | 1 | connectors | AISI 4130 plate 6 mm | Welded to chassis; 2x M8 8.8 + nyloc to bumper tab | parts/S08-CON-07A_Side_R_connector_chassis_tab.step
S08-CON-07B | Side R connector bumper tab | 1 | connectors | AISI 4130 plate 6 mm | Welded to bumper tube; bolts to chassis tab | parts/S08-CON-07B_Side_R_connector_bumper_tab.step
S08-CON-08A | Side R connector chassis tab | 1 | connectors | AISI 4130 plate 6 mm | Welded to chassis; 2x M8 8.8 + nyloc to bumper tab | parts/S08-CON-08A_Side_R_connector_chassis_tab.step
S08-CON-08B | Side R connector bumper tab | 1 | connectors | AISI 4130 plate 6 mm | Welded to bumper tube; bolts to chassis tab | parts/S08-CON-08B_Side_R_connector_bumper_tab.step
C-COL-01 | Radiator with electric fan | 1 | cooling | Bought out (R15 V2 radiator) + 7in fan | Behind firewall in engine mounting area (rule 6.2.3) | ../common/parts/C-COL-01_Radiator_with_electric_fan.step
C-COL-02 | Coolant reservoir bottle | 1 | cooling | HDPE bottle (bought out) | In fuel mounting area as required (rule 6.2.3) | ../common/parts/C-COL-02_Coolant_reservoir_bottle.step
C-DRV-02 | Axle bearing 40mm 3-bolt flange | 3 | drivetrain | Cast iron housing, 6208 insert | 3-bolt flange bearing, M10 bolts on PCD 98 | ../common/parts/C-DRV-02_Axle_bearing_40mm_3_bolt_flange.step
C-DRV-03 | Axle bearing hanger plate 6mm | 3 | drivetrain | AISI 4130 plate 6 mm | Welded to rear bulkhead and axle cross member (x3) | ../common/parts/C-DRV-03_Axle_bearing_hanger_plate_6mm.step
C-DRV-04 | Engine sprocket 14T 428 | 1 | drivetrain | C45 steel, induction hardened | 14T #428, PCD 57.1 mm | ../common/parts/C-DRV-04_Engine_sprocket_14T_428.step
C-DRV-05 | Axle sprocket 34T 428 | 1 | drivetrain | C45 steel, induction hardened | 34T #428, PCD 137.6 mm | ../common/parts/C-DRV-05_Axle_sprocket_34T_428.step
C-DRV-06 | Sprocket carrier 40mm keyed | 1 | drivetrain | Al 7075-T6 | Keyed clamp hub for 34T sprocket | ../common/parts/C-DRV-06_Sprocket_carrier_40mm_keyed.step
C-DRV-07 | Chain 428 66 links | 1 | drivetrain | Steel roller chain #428 (bought out) | Centre distance 263.6 mm, 65.99 pitches | ../common/parts/C-DRV-07_Chain_428_66_links.step
C-DRV-08 | Scatter shield chain guard | 1 | drivetrain | Aluminium 5052 1.5 mm | Rule 6.4.3 - rigidly bolted to chassis tabs, no contact with moving parts | ../common/parts/C-DRV-08_Scatter_shield_chain_guard.step
S08-DRV-01 | Rear axle 40x4 L1147 | 1 | drivetrain | EN24 / 4140 steel tube 40 x 4 | Live axle, length 1147 mm | parts/S08-DRV-01_Rear_axle_40x4_L1147.step
C-ELE-01 | 12V 5Ah sealed battery | 1 | electrics | Sealed AGM 12 V 5 Ah (YTX5L) | Aux battery <= 12 V 10 Ah (rule 6.3.1) | ../common/parts/C-ELE-01_12V_5Ah_sealed_battery.step
C-ELE-02 | Battery and ECU tray | 1 | electrics | AISI 4130 2 mm | Bolted to battery support member | ../common/parts/C-ELE-02_Battery_and_ECU_tray.step
C-ELE-03 | ECU and fuse box (blade fuses) | 1 | electrics | Bought out | Automotive blade fuses on every LV circuit (rule 6.6) | ../common/parts/C-ELE-03_ECU_and_fuse_box_blade_fuses.step
C-ENG-01 | Yamaha R15 V2 engine envelope 150cc | 1 | engine | Bought out - Yamaha R15 V2 149.8 cc single cyl 4-stroke liquid cooled | Envelope model (+/-10 mm). Engine number pad on left side faces the cockpit side for inspection. | ../common/parts/C-ENG-01_Yamaha_R15_V2_engine_envelope_150cc.step
C-ENG-02 | Engine mount bracket 5mm + isolator | 4 | engine | AISI 4130 plate 6 mm (>= 5 mm rule 6.2.2) | Welded to cradle tube; M10 bolt through rubber isolator | ../common/parts/C-ENG-02_Engine_mount_bracket_5mm_isolator.step
C-ENG-03 | Anti-vibration rubber mount 34x15 | 4 | engine | Natural rubber 60 Sh A | Vibration damping (rule 6.2.2) | ../common/parts/C-ENG-03_Anti_vibration_rubber_mount_34x15.step
C-GEA-01 | Gear lever with linkage | 1 | engine | AISI 4130 bar + rod ends | Rigidly mounted pivot (rule 6.4.1); passes over the low front section of the firewall | ../common/parts/C-GEA-01_Gear_lever_with_linkage.step
C-EXH-01 | Exhaust header 32mm | 1 | exhaust | SS304 32 x 1.5 | Ceramic-wrapped; runs outboard above the engine-bay rail | ../common/parts/C-EXH-01_Exhaust_header_32mm.step
C-EXH-02 | Silencer with rear outlet | 1 | exhaust | SS304, < 120 dB | Outlet behind driver at 370 mm height (rule 6.2.4 <= 650 mm) | ../common/parts/C-EXH-02_Silencer_with_rear_outlet.step
C-EXH-03 | Exhaust heat shield | 1 | exhaust | Perforated SS 0.8 mm | Shields muffler outboard/top (rule 6.2.4) | ../common/parts/C-EXH-03_Exhaust_heat_shield.step
C-FST-01 | Bolt M8x30 8.8 hex (Z) | 8 | fasteners | ISO 4017 M8 grade 8.8 zinc | Rule 6.10 - metric grade 8.8 | ../common/parts/C-FST-01_Bolt_M8x30_8_8_hex_Z.step
C-FST-02 | Bolt M8x30 8.8 hex (X) | 8 | fasteners | ISO 4017 M8 grade 8.8 zinc | Rule 6.10 - metric grade 8.8 | ../common/parts/C-FST-02_Bolt_M8x30_8_8_hex_X.step
C-FST-03 | Nut M8 nyloc (Z) | 8 | fasteners | ISO 10511 M8 class 8 | Lock nut (rule 6.10) | ../common/parts/C-FST-03_Nut_M8_nyloc_Z.step
C-FST-04 | Nut M8 nyloc (X) | 8 | fasteners | ISO 10511 M8 class 8 | Lock nut (rule 6.10) | ../common/parts/C-FST-04_Nut_M8_nyloc_X.step
C-FWL-01 | Firewall side panel 1.5mm | 1 | firewall | Aluminium 5052 1.5 mm | Seals driver from engine/chain on the right; no holes, nothing mounted on it (rule 3.5) | ../common/parts/C-FWL-01_Firewall_side_panel_1_5mm.step
C-FWL-02 | Firewall rear panel 1.5mm | 1 | firewall | Aluminium 5052 1.5 mm | Behind seat on rear face of roll hoop; seals driver's back (rule 3.5) | ../common/parts/C-FWL-02_Firewall_rear_panel_1_5mm.step
C-FWL-03 | Anti-intrusion plate 2mm | 1 | firewall | Aluminium 6061-T6 2 mm | Bolted to foot guard (rule 3.2) | ../common/parts/C-FWL-03_Anti_intrusion_plate_2mm.step
S08-FRM-01 | Main frame Endurance | 1 | frame | AISI 4130 chromoly, seamless (C 0.28-0.33 %) | 33 members, 20.7 m of 25.4x1.65 tube (~20.0 kg tube mass), multi-body weldment | parts/S08-FRM-01_Main_frame_Endurance.step
C-FUE-01 | Fuel tank 2.79L aluminium | 1 | fuel | Al 5052 2 mm welded | Internal volume 2.79 L (rule <= 3 L); behind seat in fuel mounting area, left side | ../common/parts/C-FUE-01_Fuel_tank_2_79L_aluminium.step
C-FUE-02 | Fuel tank tray and straps | 1 | fuel | AISI 4130 2 mm + steel straps | Bolted to brace cross bar behind firewall (metal fasteners only) | ../common/parts/C-FUE-02_Fuel_tank_tray_and_straps.step
C-FUE-03 | Fuel line 8mm with clamps | 1 | fuel | Fuel-rated hose + metal P-clips | Rigidly clamped to frame (rule 6.2.3) | ../common/parts/C-FUE-03_Fuel_line_8mm_with_clamps.step
C-HIT-01 | Hitch eye 8mm yellow | 2 | hitch | AISI 4130 plate 8 mm, yellow paint | Front and rear hitch points, not on bumper, separate from jack points (rule 1.4) | ../common/parts/C-HIT-01_Hitch_eye_8mm_yellow.step
C-PED-01 | Clutch pedal | 1 | pedals | Al 6061-T6 / AISI 4130 (brake) | Hanging pedal on 16 mm shaft, pad at Z=-160 (CBA left to right, rule 6.4.2) | ../common/parts/C-PED-01_Clutch_pedal.step
C-PED-02 | Brake pedal | 1 | pedals | Al 6061-T6 / AISI 4130 (brake) | Hanging pedal on 16 mm shaft, pad at Z=-10 (CBA left to right, rule 6.4.2) | ../common/parts/C-PED-02_Brake_pedal.step
C-PED-03 | Throttle pedal | 1 | pedals | Al 6061-T6 / AISI 4130 (brake) | Hanging pedal on 16 mm shaft, pad at Z=80 (CBA left to right, rule 6.4.2) | ../common/parts/C-PED-03_Throttle_pedal.step
C-PED-04 | Pedal shaft, hangers and pedal stops | 1 | pedals | AISI 4130 | Hangers welded to foot-guard cross bar; stops limit pedal travel (rule 5.2, 6.4.2) | ../common/parts/C-PED-04_Pedal_shaft_hangers_and_pedal_stops.step
S08-REF-01 | REF driver 175cm (not manufactured) | 1 | reference | Reference geometry only | 175 cm male, back 20 deg, helmet top for roll-hoop check | parts/S08-REF-01_REF_driver_175cm_not_manufactured.step
C-SAF-01 | Kill switch enclosure | 3 | safety | Bought out, IP65 | Rule 6.5 - push-off twist-release; mount on hinge tab welded to chassis | ../common/parts/C-SAF-01_Kill_switch_enclosure.step
C-SAF-01B | Kill switch red mushroom head | 3 | safety | Bought out | Part of C-SAF-01 | ../common/parts/C-SAF-01B_Kill_switch_red_mushroom_head.step
C-SAF-02 | Kill switch mounting hinge tab | 3 | safety | AISI 4130 plate 6 mm | Welded to chassis tube (rule 6.5) | ../common/parts/C-SAF-02_Kill_switch_mounting_hinge_tab.step
C-SAF-03 | Brake light LED red | 1 | safety | Bought out 12 V LED | Top centre of roll hoop (rule 5.6) | ../common/parts/C-SAF-03_Brake_light_LED_red.step
C-SAF-03L | Brake light lens | 1 | safety | Polycarbonate red | Part of C-SAF-03 | ../common/parts/C-SAF-03L_Brake_light_lens.step
C-SAF-04 | Fire extinguisher 1kg ABC | 1 | safety | Bought out 1 kg ABC dry powder | Rigidly mounted in driver compartment, not on firewall (rule 6.9) | ../common/parts/C-SAF-04_Fire_extinguisher_1kg_ABC.step
C-SAF-05 | Extinguisher quick-release bracket | 1 | safety | Steel, Drake-type QR | Welded to left main rail | ../common/parts/C-SAF-05_Extinguisher_quick_release_bracket.step
C-SEA-01 | Bucket seat 360 fibreglass | 1 | seat | GRP fibreglass 5 mm | Back angle 20 deg from vertical (rule <= 30); 4 mounts (rule 3.1) | ../common/parts/C-SEA-01_Bucket_seat_360_fibreglass.step
C-SEA-02 | Seat front mount block | 2 | seat | AISI 4130 5 mm plate stack | Welded on seat cross member (primary member), M8 + nyloc | ../common/parts/C-SEA-02_Seat_front_mount_block.step
C-SEA-03 | Seat back mount tab | 2 | seat | AISI 4130 plate 6 mm | Welded on roll-hoop cross bar, M8 + nyloc | ../common/parts/C-SEA-03_Seat_back_mount_tab.step
C-STR-01 | Steering column 22x3 | 1 | steering | AISI 4130 tube 22 x 3 | Length 537 mm, 33 deg below horizontal | ../common/parts/C-STR-01_Steering_column_22x3.step
C-STR-02 | Steering wheel 280 OD round | 1 | steering | Aluminium spokes, leather-wrapped rim | Full circle 280 mm OD (rule 4.2 >= 254 mm), quick-release hub | ../common/parts/C-STR-02_Steering_wheel_280_OD_round.step
C-STR-03 | Pitman steering arm 8mm | 1 | steering | AISI 4130 plate 8 mm | Welded to column, tie-rod pad at R90 (2x M8 vertical) | ../common/parts/C-STR-03_Pitman_steering_arm_8mm.step
C-STR-04 | Column upper bearing bracket | 1 | steering | AISI 4130 + bronze bush | Bolted to dash bar (2x M8) | ../common/parts/C-STR-04_Column_upper_bearing_bracket.step
C-STR-05 | Column lower bracket with steering stops | 1 | steering | AISI 4130 plate 8 mm | Welded to front axle beam; M10 stop bolts stop the pitman arm at 52 deg (just past full lock) | ../common/parts/C-STR-05_Column_lower_bracket_with_steering_stops.step
C-STR-06 | King pin bolt M10x130 + nyloc | 2 | steering | Grade 10.9 bolt + Nyloc nut | Caster 10 deg | ../common/parts/C-STR-06_King_pin_bolt_M10x130_nyloc.step
S08-STR-11 | Steering knuckle left | 1 | steering | AISI 4130 (boss + 20 mm stub axle + 8 mm arm) | Arm 155 mm at 15.25 deg (Ackermann tuned), caster 10 deg | parts/S08-STR-11_Steering_knuckle_left.step
S08-STR-12 | Steering knuckle right | 1 | steering | AISI 4130 (boss + 20 mm stub axle + 8 mm arm) | Arm 155 mm at 15.25 deg (Ackermann tuned), caster 10 deg | parts/S08-STR-12_Steering_knuckle_right.step
S08-STR-13 | Tie rod left C-C 277 | 1 | steering | M10 rod ends + 12 mm steel rod, LH/RH thread | Centre-to-centre 276.7 mm (adjustable +-10) | parts/S08-STR-13_Tie_rod_left_C_C_277.step
S08-STR-14 | Tie rod right C-C 396 | 1 | steering | M10 rod ends + 12 mm steel rod, LH/RH thread | Centre-to-centre 396.5 mm (adjustable +-10) | parts/S08-STR-14_Tie_rod_right_C_C_396.step
C-WHL-01 | Front tyre 4.5x10.0-5 slick | 2 | wheels | Rubber (bought out) | Rule 2.2 table 1 dry tyre 4.5x10.0-5 | ../common/parts/C-WHL-01_Front_tyre_4_5x10_0_5_slick.step
C-WHL-02 | Rear tyre 7.1x11.0-5 slick | 2 | wheels | Rubber (bought out) | Rule 2.2 table 1 dry tyre 7.1x11.0-5 | ../common/parts/C-WHL-02_Rear_tyre_7_1x11_0_5_slick.step
C-WHL-03 | Front rim 5in x 4.5 | 2 | wheels | Cast aluminium A356-T6 | Bolts to hub with 3x M8 on PCD 58 | ../common/parts/C-WHL-03_Front_rim_5in_x_4_5.step
C-WHL-04 | Rear rim 5in x 7.1 | 2 | wheels | Cast aluminium A356-T6 | Bolts to hub with 3x M8 on PCD 58 | ../common/parts/C-WHL-04_Rear_rim_5in_x_7_1.step
C-WHL-05 | Front hub 20mm | 2 | wheels | EN8 steel | Front hub on stub axle, 3x M8 studs PCD 58 | ../common/parts/C-WHL-05_Front_hub_20mm.step
C-WHL-06 | Rear hub 40mm keyed | 2 | wheels | Al 7075-T6 | Keyed clamp hub on 40 mm axle | ../common/parts/C-WHL-06_Rear_hub_40mm_keyed.step

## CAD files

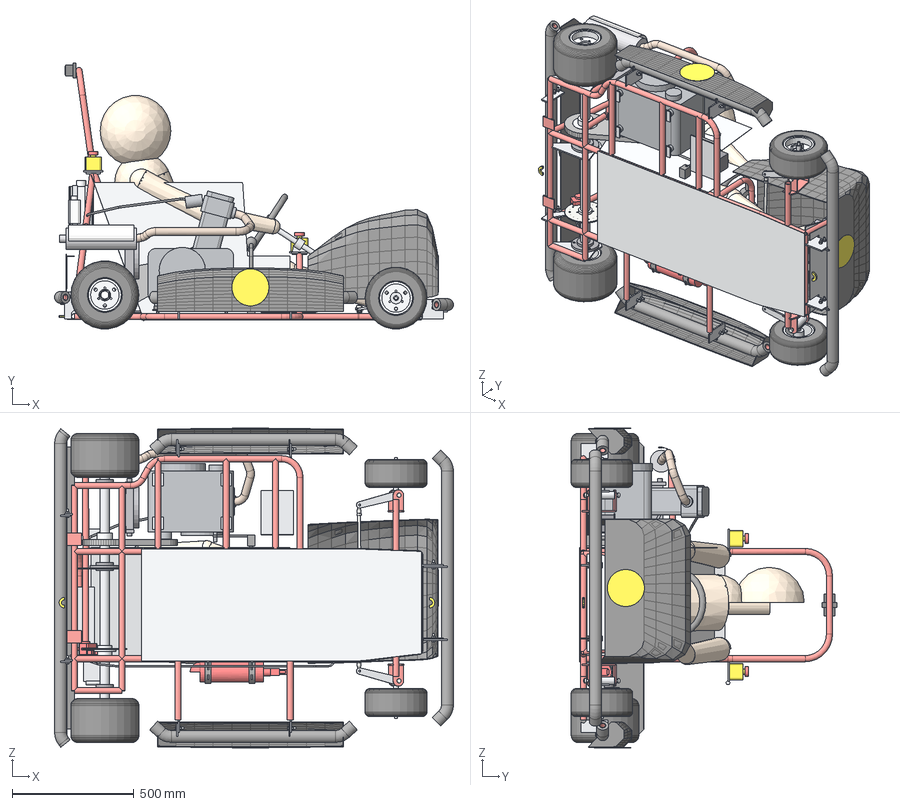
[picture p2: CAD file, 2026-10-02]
output/S01_ClassicSprint/S01_ClassicSprint_ASSEMBLY.step
1635.9 x 1089.1 x 1310.1 mm
S01-FRM-01_Main_frame_Classic_Sprint
S01-BOD-10_Floor_close_out_pan_2mm
S01-BMP-01_Front_bumper
S01-BMP-02_Rear_bumper
S01-BMP-05_Front_bumper_foam
S01-BMP-06_Rear_bumper_foam
S01-BMP-03_Side_bumper_left
S01-BMP-07_Side_bumper_left_foam
S01-BMP-04_Side_bumper_right
S01-BMP-08_Side_bumper_right_foam
S01-CON-01A_Front_connector_chassis_tab
S01-CON-01B_Front_connector_bumper_tab
C-FST-01_Bolt_M8x30_8_8_hex_Z x 8
C-FST-03_Nut_M8_nyloc_Z x 8
S01-CON-02A_Front_connector_chassis_tab
S01-CON-02B_Front_connector_bumper_tab
S01-CON-03A_Rear_connector_chassis_tab
S01-CON-03B_Rear_connector_bumper_tab
S01-CON-04A_Rear_connector_chassis_tab
S01-CON-04B_Rear_connector_bumper_tab
S01-CON-05A_Side_L_connector_chassis_tab
S01-CON-05B_Side_L_connector_bumper_tab
C-FST-02_Bolt_M8x30_8_8_hex_X x 8
C-FST-04_Nut_M8_nyloc_X x 8
S01-CON-07A_Side_R_connector_chassis_tab
S01-CON-07B_Side_R_connector_bumper_tab
S01-CON-06A_Side_L_connector_chassis_tab
S01-CON-06B_Side_L_connector_bumper_tab
S01-CON-08A_Side_R_connector_chassis_tab
S01-CON-08B_Side_R_connector_bumper_tab
C-WHL-01_Front_tyre_4_5x10_0_5_slick x 2
C-WHL-03_Front_rim_5in_x_4_5 x 2
C-WHL-05_Front_hub_20mm x 2
C-WHL-02_Rear_tyre_7_1x11_0_5_slick x 2
C-WHL-04_Rear_rim_5in_x_7_1 x 2
C-WHL-06_Rear_hub_40mm_keyed x 2
S01-STR-11_Steering_knuckle_left
S01-STR-13_Tie_rod_left_C_C_271
C-STR-06_King_pin_bolt_M10x130_nyloc x 2
S01-STR-12_Steering_knuckle_right
S01-STR-14_Tie_rod_right_C_C_391
C-STR-01_Steering_column_22x3
C-STR-02_Steering_wheel_280_OD_round
C-STR-03_Pitman_steering_arm_8mm
C-STR-04_Column_upper_bearing_bracket
C-STR-05_Column_lower_bracket_with_steering_stops
S01-DRV-01_Rear_axle_40x4_L1147
C-DRV-03_Axle_bearing_hanger_plate_6mm x 3
C-DRV-02_Axle_bearing_40mm_3_bolt_flange x 3
C-DRV-05_Axle_sprocket_34T_428
C-DRV-06_Sprocket_carrier_40mm_keyed
C-DRV-04_Engine_sprocket_14T_428
C-DRV-07_Chain_428_66_links
C-DRV-08_Scatter_shield_chain_guard
C-BRK-01_Brake_disc_180x5
C-BRK-02_Disc_carrier_40mm_keyed
C-BRK-03_Brake_caliper_twin_piston
C-BRK-04_Caliper_mounting_bracket_6mm
C-BRK-05_Brake_master_cylinder_5_8in_with_reservoir
C-BRK-06_Master_cylinder_bracket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

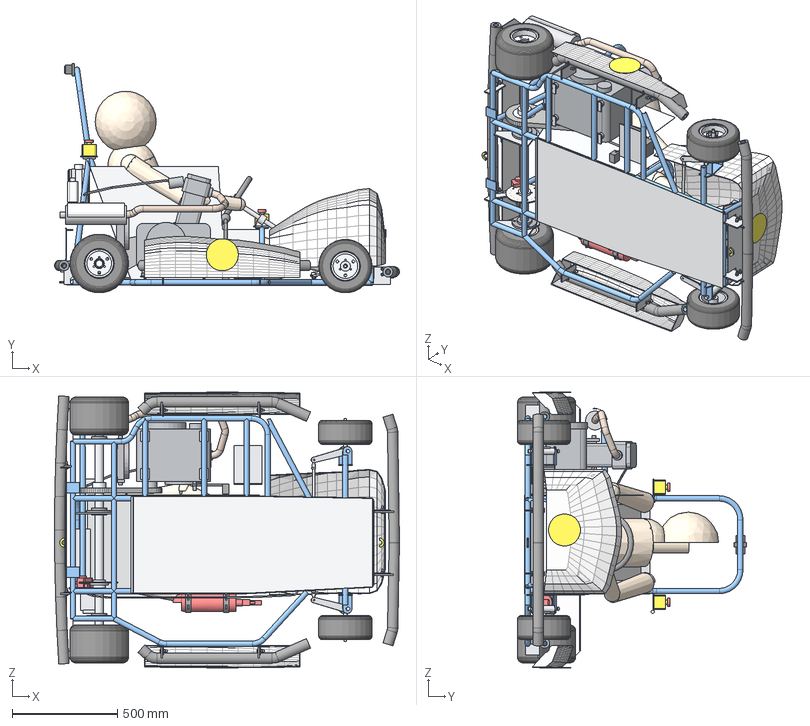
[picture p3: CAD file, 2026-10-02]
output/S02_Arrow/S02_Arrow_ASSEMBLY.step
1637.8 x 1089.1 x 1308.6 mm
S02-FRM-01_Main_frame_Arrow
S02-BOD-10_Floor_close_out_pan_2mm
S02-BMP-01_Front_bumper
S02-BMP-02_Rear_bumper
S02-BMP-05_Front_bumper_foam
S02-BMP-06_Rear_bumper_foam
S02-BMP-03_Side_bumper_left
S02-BMP-07_Side_bumper_left_foam
S02-BMP-04_Side_bumper_right
S02-BMP-08_Side_bumper_right_foam
S02-CON-01A_Front_connector_chassis_tab
S02-CON-01B_Front_connector_bumper_tab
C-FST-01_Bolt_M8x30_8_8_hex_Z x 8
C-FST-03_Nut_M8_nyloc_Z x 8
S02-CON-02A_Front_connector_chassis_tab
S02-CON-02B_Front_connector_bumper_tab
S02-CON-03A_Rear_connector_chassis_tab
S02-CON-03B_Rear_connector_bumper_tab
S02-CON-04A_Rear_connector_chassis_tab
S02-CON-04B_Rear_connector_bumper_tab
S02-CON-05A_Side_L_connector_chassis_tab
S02-CON-05B_Side_L_connector_bumper_tab
C-FST-02_Bolt_M8x30_8_8_hex_X x 8
C-FST-04_Nut_M8_nyloc_X x 8
S02-CON-07A_Side_R_connector_chassis_tab
S02-CON-07B_Side_R_connector_bumper_tab
S02-CON-06A_Side_L_connector_chassis_tab
S02-CON-06B_Side_L_connector_bumper_tab
S02-CON-08A_Side_R_connector_chassis_tab
S02-CON-08B_Side_R_connector_bumper_tab
C-WHL-01_Front_tyre_4_5x10_0_5_slick x 2
C-WHL-03_Front_rim_5in_x_4_5 x 2
C-WHL-05_Front_hub_20mm x 2
C-WHL-02_Rear_tyre_7_1x11_0_5_slick x 2
C-WHL-04_Rear_rim_5in_x_7_1 x 2
C-WHL-06_Rear_hub_40mm_keyed x 2
S02-STR-11_Steering_knuckle_left
S02-STR-13_Tie_rod_left_C_C_263
C-STR-06_King_pin_bolt_M10x130_nyloc x 2
S02-STR-12_Steering_knuckle_right
S02-STR-14_Tie_rod_right_C_C_383
C-STR-01_Steering_column_22x3
C-STR-02_Steering_wheel_280_OD_round
C-STR-03_Pitman_steering_arm_8mm
C-STR-04_Column_upper_bearing_bracket
C-STR-05_Column_lower_bracket_with_steering_stops
S02-DRV-01_Rear_axle_40x4_L1142
C-DRV-03_Axle_bearing_hanger_plate_6mm x 3
C-DRV-02_Axle_bearing_40mm_3_bolt_flange x 3
C-DRV-05_Axle_sprocket_34T_428
C-DRV-06_Sprocket_carrier_40mm_keyed
C-DRV-04_Engine_sprocket_14T_428
C-DRV-07_Chain_428_66_links
C-DRV-08_Scatter_shield_chain_guard
C-BRK-01_Brake_disc_180x5
C-BRK-02_Disc_carrier_40mm_keyed
C-BRK-03_Brake_caliper_twin_piston
C-BRK-04_Caliper_mounting_bracket_6mm
C-BRK-05_Brake_master_cylinder_5_8in_with_reservoir
C-BRK-06_Master_cylinder_bracket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

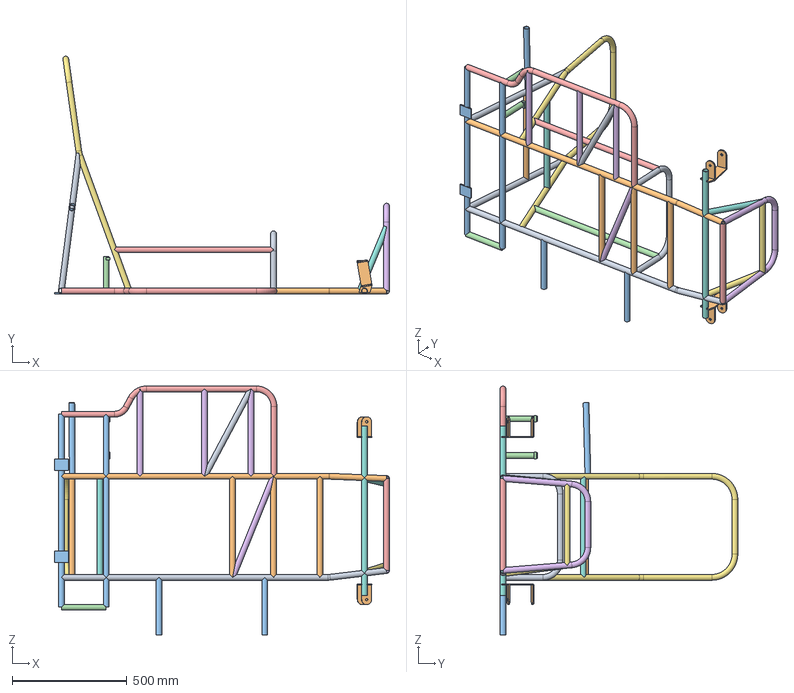
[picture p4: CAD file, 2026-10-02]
output/S08_Endurance/parts/S08-FRM-01_Main_frame_Endurance.step
1457.7 x 1034.6 x 1083.4 mm

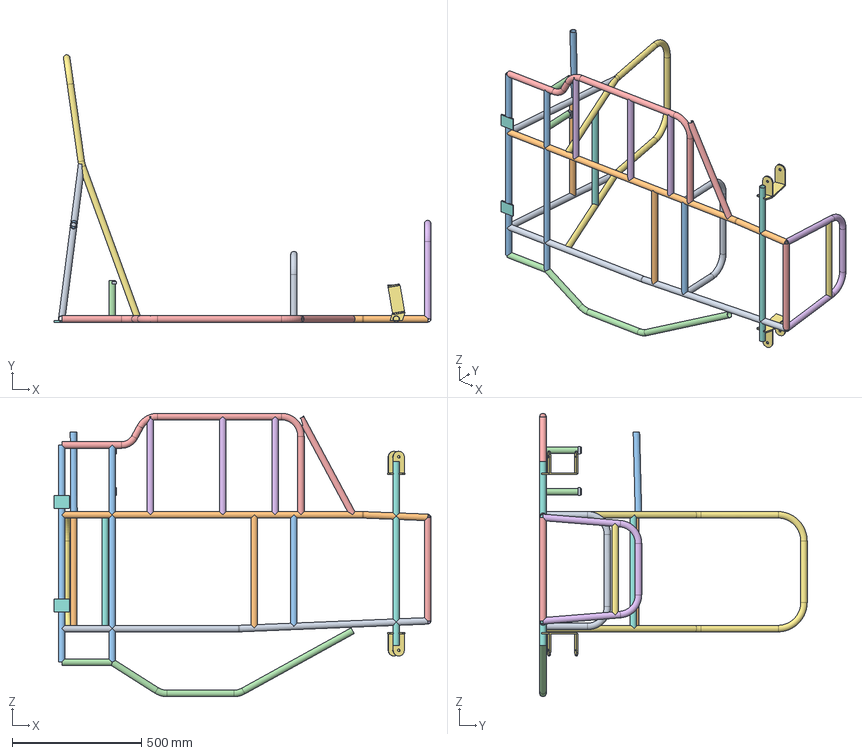
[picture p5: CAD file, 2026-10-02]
output/S10_Wedge/parts/S10-FRM-01_Main_frame_Wedge.step
1457.7 x 1034.6 x 1096.1 mm

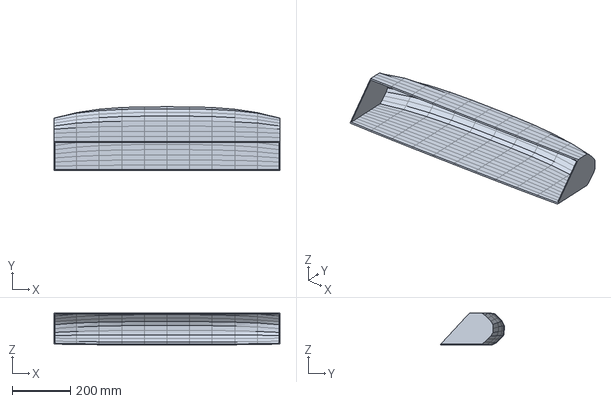
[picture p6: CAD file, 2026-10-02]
output/S08_Endurance/parts/S08-BOD-02_Side_pod_left_full.step
778.8 x 219.0 x 110.0 mm

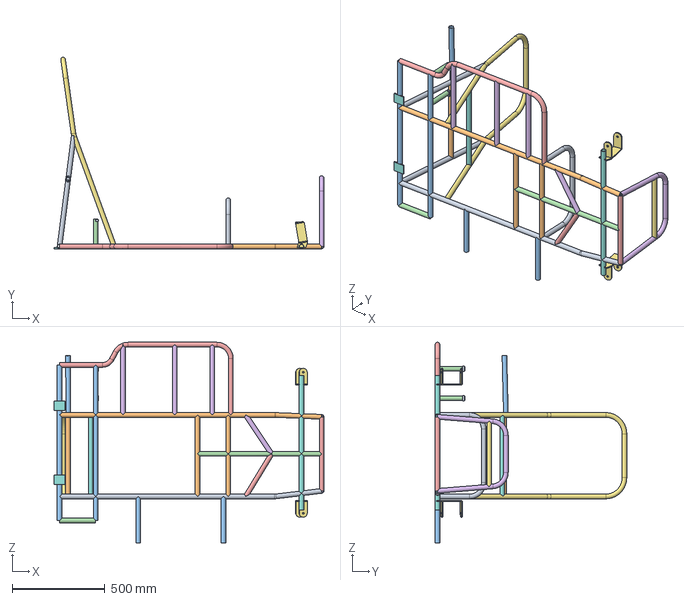
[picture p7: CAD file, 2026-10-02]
output/S07_Spine/parts/S07-FRM-01_Main_frame_Spine.step
1457.7 x 1034.6 x 1082.7 mm

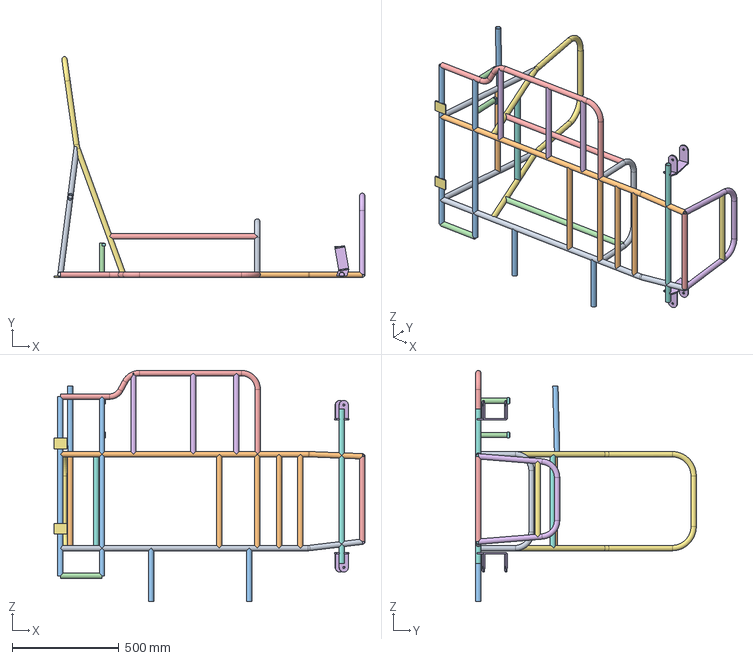
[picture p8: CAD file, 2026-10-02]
output/S03_LadderPro/parts/S03-FRM-01_Main_frame_Ladder_Pro.step
1457.7 x 1034.6 x 1083.4 mm

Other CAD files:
output/S03_LadderPro/S03_LadderPro_ASSEMBLY.step
output/S04_Bowfin/S04_Bowfin_ASSEMBLY.step
output/S05_X-Brace/S05_X-Brace_ASSEMBLY.step
output/S06_Perimeter/S06_Perimeter_ASSEMBLY.step
output/S07_Spine/S07_Spine_ASSEMBLY.step
output/S08_Endurance/S08_Endurance_ASSEMBLY.step
output/S09_Featherweight/S09_Featherweight_ASSEMBLY.step
output/S10_Wedge/S10_Wedge_ASSEMBLY.step
output/S02_Arrow/parts/S02-FRM-01_Main_frame_Arrow.step
output/S04_Bowfin/parts/S04-FRM-01_Main_frame_Bowfin.step
output/S06_Perimeter/parts/S06-BOD-02_Side_pod_left_full.step
output/S01_ClassicSprint/parts/S01-BMP-01_Front_bumper.step
output/S01_ClassicSprint/parts/S01-BMP-02_Rear_bumper.step
output/S01_ClassicSprint/parts/S01-BMP-03_Side_bumper_left.step
output/S01_ClassicSprint/parts/S01-BMP-04_Side_bumper_right.step
output/S01_ClassicSprint/parts/S01-BMP-05_Front_bumper_foam.step
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

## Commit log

2026-10-01 Add parametric generator for 10 EKVC Season 4 engine-kart styles
    CadQuery generator that builds ten complete side-engine (Yamaha R15 V2)
    karts from the team's steering sketch: chromoly frames, roll hoop,
    front/rear/side bumpers with bolted chassis connectors, single-disc
    hydraulic brake, live axle and chain drive, Ackermann steering solved
    per style, pedal box, seat, firewall, bodywork and safety parts.
    Includes automated EKVC Season 4 rule checks, interference and
    swept-tyre clash detection, STEP export with placement tables, and a
    SolidWorks VBA macro that converts the STEP set to SLDPRT/SLDASM.
    Claude-Session: https://claude.ai/cod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
2026-10-01 Generate 10 rule-checked kart styles: STEP parts, assemblies, BOMs, reports
    All ten styles pass the 45 automated EKVC Season 4 checks with no
    part clashes and no swept-tyre contacts; bumper-to-bumper length
    64.1-64.6 in. Each style folder holds its part STEPs, a full assembly
    STEP, placements.csv for the SolidWorks macro, BOM.csv, a compliance
    README and renders. Also adds the kart stand and push-pull rod, and
    tapers the foot-guard top so every nose shape clears it.
    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
    [BOM.csv, C-BOD-01_Kart_number_sticker_6in_yellow_X.step, C-BOD-02_Kart_number_sticker_6in_yellow_Z.step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]
2026-10-01 Add chassis-only STEP export (frame, roll hoop, welded tabs) for all 10 styles
    Claude-Session: https://claude.ai/code/session_01EHTgTDFz5ryGDUMgrGMctu
    [S01_ClassicSprint_Chassis.step, S02_Arrow_Chassis.step, S03_LadderPro_Chassis.step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]
2026-10-02 Steering: real rod-end joint centres, re-tuned Ackermann, stop and bracket clearance, live-steering mates
    - Solver now uses the rod-end ball centres (9 mm below the pitman pad, 9 mm above the
    knuckle arm), the same points the CAD tie rods use; arm angle re-tuned per style
    (15.0-16.25 deg) for ~100 % Ackermann at lock.
    - Steering stops act at 52 deg column rotation (were blocking at ~25 deg).
    - Lower column bracket redesigned clear of the pitman arm over the full range; king-pin
    C-bracket web moved to 66 mm inboard, clear of the knuckle arm at full lock.
    - New lock-to-lock check of the whole steering linkage against the kart.
    - kinematics.csv export + SolidWorks macro: KIN_ joint sketch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
2026-10-02 Rebuild S01-S04 and common parts with corrected steering and live-steering kinematics
    45/45 rules, 0 clashes, 0 tyre-sweep and 0 linkage-sweep contacts on each.
    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
    [BOM.csv, C-BOD-01_Kart_number_sticker_6in_yellow_X.step, C-BOD-02_Kart_number_sticker_6in_yellow_Z.step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]
2026-10-02 Rebuild S07 with corrected steering and live-steering kinematics
    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
    [BOM.csv, S07-BMP-01_Front_bumper.step, S07-BMP-02_Rear_bumper.step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]
2026-10-02 Rebuild S06 with corrected steering and live-steering kinematics
    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
    [BOM.csv, S06-BMP-01_Front_bumper.step, S06-BMP-02_Rear_bumper.step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]
2026-10-02 Nose side walls stay inboard of the king-pin C-bracket webs on narrow-track karts
    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
2026-10-02 Remove superseded tie-rod STEP files; build now prunes unused style parts
    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
    [S01-STR-13_Tie_rod_left_C_C_292.step, S01-STR-14_Tie_rod_right_C_C_412.step, S02-STR-13_Tie_rod_left_C_C_283.step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]
2026-10-02 Rebuild S05, S09, S10 with corrected steering and live-steering kinematics
    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
    [BOM.csv, C-BOD-01_Kart_number_sticker_6in_yellow_X.step, C-BOD-02_Kart_number_sticker_6in_yellow_Z.step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]
2026-10-02 S08 foot-guard braces land just behind the front axle beam, clear of the knuckle arms at lock
    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
2026-10-02 README: live steering in SolidWorks, corrected steering spec and linkage-sweep results
    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
2026-10-02 Rebuild S08 (foot-guard brace fix) and re-export chassis-only parts for all 10 styles
    All ten karts: 45/45 rules, 0 clashes, 0 tyre-sweep and 0 linkage-sweep contacts.
    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
    [BOM.csv, S01_ClassicSprint_Chassis.step, S02_Arrow_Chassis.step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]
